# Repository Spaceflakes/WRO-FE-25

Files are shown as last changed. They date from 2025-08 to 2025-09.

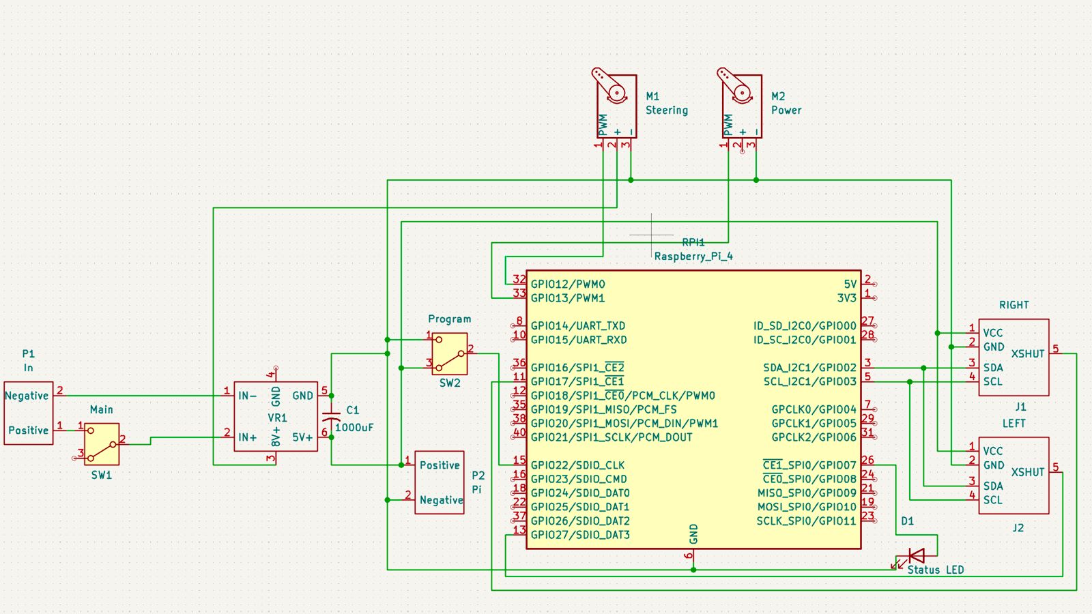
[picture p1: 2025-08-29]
schemes/Schematic Diagram.jpeg

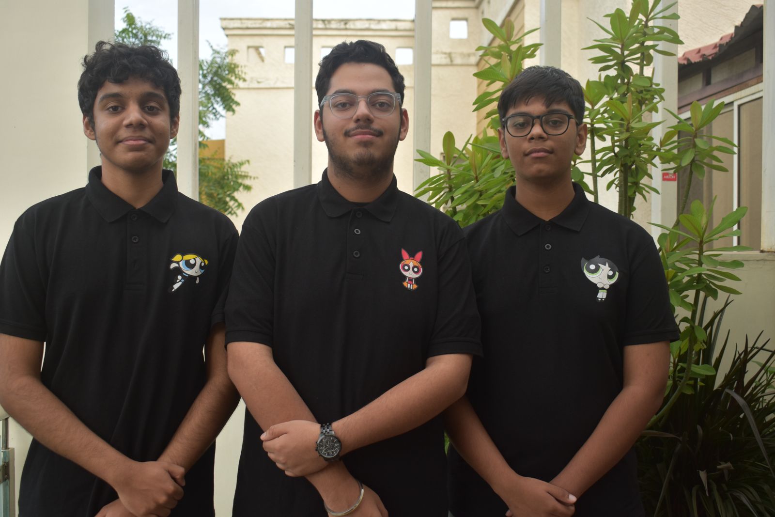
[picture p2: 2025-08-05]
t-photos/Formal.jpg

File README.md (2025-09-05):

<div align="center">
	
# WRO-25

# The Powerpuff Trio

Powerpuff_girls_wallpaper-removebg-preview

**_The offical repo of The Powerpuff trio for WRO-FE 2025_**
</div>
	
## Content
### **Folders**
* `t-photos` contains 1 formal image and 2 informal images
* `v-photos` contains 6 photos of the vehicle (from every side, from top and bottom)
* `video` contains the video.md file with the link to a video where driving demonstration exists
* `schemes` contains schematic diagrams of components illustrating all the elements (electronic components and motors) used in the vehicle and how they connect to each other, along with the models of the PCB.
* `src` contains code of control software for all components which were programmed to participate in the competition
* `models` is for the files for 3D models used by to produce the vehicle elements.

### **Index**
 [The Powerpuff Trio](#The-Powerpuff-Trio) 
   
   - Members
   
   - Small introduction to them

   - Team Pictures

[Vehicle Photos and Video](#Vehicle-Photos-and-Video)

- Shows the vehicle from all 6 sides and shows a smaple video of it working
   
 [Hardware Materials](#Hardware-Materials)

 - Name of parts

 - Links

 - Rate per part

 [Mobility Management](#Mobility-Management)
 
 - Gives an overview of our bots parts

[Design](#Design)

- Tells how every component is placed. 

[Power Management and Sense Management](#Power-Management-and-Sense-Management)

  - Gives an overview about the power consumption of our bot and use of each sensor

[Schematic Diagram](#Schematic-Diagram)

 - Shows all connections between the parts

[Obstacle Management](#Obstacle-Management)

- Basic overview of our strategy

- Shows our logic for dectecing the pillars and parking logic

[Our Journal](#Our-Journal)

- Tells our jounery making the bot

## The Powerpuff Trio 
Members:
1) Vedant Varshney

11th Grader in Billabong High International School. First time participating in WRO but has participated many other robotic compenitions. Controlling the making of the github  and helping in other miscellaneous tasks

2) Siddesh Jain

11th Grader in Billabong High, second time in WRO, the lead engineer and the head of the developement team, responsible for the CAD and all the choices. Races FPV drones and likes math. Also is an idiot.
   
3) Sohaan Chhabra

A 12th grader at Billabong High International School. Returning WRO participant. Handles the logic, simulations, camera and LiDAR processing — basically speaks to AI more than humans. Also, races drones just to relax.

### Team Pictures

#### Formal



#### Informal



Informal - 2

# Vehicle Photos and Video

#### Photos

Back View

Front view

Side View 2

Side View 1

Bottom View

Top View

> [!NOTE]
> We replaced the zipties that strapped on the batteries to the bot with velcro straps.

#### Videos

https://youtu.be/7fzDv5zbyI8?si=_J0dI-LTaZbQbC20

## Hardware Materials

| Name |	Link |	Rate per part (in Rs.) |
|---|---|---|
| Rpi 4B/5	| https://www.raspberrypi.com/products/raspberry-pi-5 | -	|	
| LiDAR	| https://robu.in/product/ydlidar-x4-pro-360-degree-ros-scanner-for-navigation-collision-avoidance-10m/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	| 8159 |	
| Servo	| https://robu.in/product/surpass-hobby-25kg-s2500m-servo/	| 1500 |	
| Wheels |	https://robu.in/product/65mm-robot-smart-car-12-rim-wheel-blue/ |	167 |	
| Pi Camera	| https://robu.in/product/arducam-8mp-imx219-175-degree-ultra-wide-angle-raspberry-pi-camera-module-compatible-with-raspberry-pi-4-model-b-pi-3-3b-and-pi-zero-2w/ |	2090	|	
|Stepdown Module | https://robu.in/product/mini560-dc-5v-5a-step-down-stabilized-module/ | 94 |		
| ESC + Motor |	https://www.hobbywingdirect.com/collections/quicrun-brushless-system/products/quicrun-wp-10bl120-sl-system-g2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 |	15000 |	
| Battery |	- |	1500 |		
| Gears | - |	2500 |		
| PCB | - |	2000 |		
| CF | - |	1500 |	

### PCB Design & Prototype PCB

##### Prototype PCB

WhatsApp Image 2025-08-23 at 5 41 59 PM

##### PCB Design





## Mobility Management

Our self-driving vehicle utilizes a rear-wheel drive (RWD) configuration, where both rear wheels are powered by a single brushless DC motor via a unified drivetrain and a robust 6:1 gear reduction. The wheels are 65 mm in diameter, providing an optimal balance between ground clearance and acceleration. Steering is accomplished using a high-torque Surpass Hobby 25kg S2500M servo mechanically linked to the front wheels through a precision steering linkage, under PWM control from a Raspberry Pi single-board computer.

The chassis is built from a unified bottom plate, providing a lightweight yet rigid foundation that maintains dimensional stability under load. All components are secured via counter-sunk steel screws, ensuring minimal chassis flex and maximum durability in high-dynamic maneuvers.

Speed, torque, and power calculations:

With a 6:1 gear reduction from the motor to the driving wheels, and a wheel diameter of 65 mm, the theoretical speed and torque can be calculated as follows:

Assume maximum motor RPM (post-gear reduction): 3000 RPM (typical for RWD brushless at this voltage/gear)

Wheel circumference: 
C = π × D

= 3.1416 × 0.065m ≈ 0.204m

At 3000 RPM at the wheel:

Linear speed: 
V = RPM × C / 60

= 3000 × 0.204 / 60 ≈ 10.2m/s  (36.7 km/h theoretical, but likely to operate at much lower speed for control and safety)

Since the gear ratio is 6:1, torque at the wheel is multiplied by 6 relative to the motor's output. If the motor provides 0.3 Nm, at the wheels this becomes 

0.3 × 6 = 1.8Nm

This setup allows for both quick acceleration and sufficient torque to manage sharp turns and inclines, which is crucial for obstacle navigation and parallel parking accuracy.

The ESC (Hobbywing Quicrun WP-10BL120, G2) regulates current delivery (up to 60A) for smooth and responsive throttle input, while PWM control from the Pi enables fine-grained speed and direction regulation.

In summary, the chassis, drivetrain, and steering are holistically integrated to provide robust, agile, and precise mobility

> [!NOTE]
> We initially selected a carbon fiber chassis for its high strength-to-weight ratio but switched to a simpler material because precise cutting was difficult with our tools. To streamline development, we also opted not to include ToF sensors, using LiDAR and Pi Camera that simplify integration while still delivering reliable obstacle detection and navigation performance, fully in line with competition rules and judging criteria.

 ## Design

We mounted the LiDAR sensor on top of the ESC to ensure that its readings remain accurate and free from interference caused by other components. Since there was limited space in the center of the robot, we attached the two batteries securely on the sides using Velcro straps, which provide both stability and ease of removal. Beneath the LiDAR, the ESC is positioned to maintain a compact arrangement. The motor is placed near the rear wheels for efficient power transmission, while the servo, responsible for steering, is located between the front wheels to allow precise control of direction. The PCB board is carefully installed between the ESC and the front wheels in its own compartment to optimize wiring and accessibility. Our robot uses wheels with a diameter of 65 mm, balancing maneuverability and stability on the track and its overall dimensions of 280 mm in length, 175 mm in width, and 95 mm in height. Additionally, the camera is mounted on the front wing, providing a clear and unobstructed view ahead to assist with navigation during the autonomous run.

## Power Management and Sense Management

The propulsion and actuation circuits (ESC, motor, servo) are supplied by one LiPo battery. The ESC has a peak draw of 60A (operating at ~50%, or 30A continuous, during typical run), consuming a maximum of 14.8V × 30A = 444 W. The servo draws 10W at peak, and the combined power budget for the actuation side is kept within the safe limits by the battery’s discharge rating.

The Raspberry Pi and sensitive sensors (including Lidar and IMU) are isolated on the second 4S LiPo, with a DC-DC converter regulating voltage to 5V/3A as required for stable logic and communication. The Pi and Lidar each typically consume 12.5W (2.5A @ 5V per spec), ensuring ample runtime and reliable operation under competition conditions.

Wire gauge and power distribution are selected to minimize resistive losses, and all high-current connections use gold-plated connectors and fuses for safety and performance.

Sensor Suite Includes:

Lidar (12.5W): Primary for localization, mapping, and pillar/tracking detection in the obstacle challenge.

Raspberry Pi Camera (CSI-2): Used for vision-based lane detection and traffic sign/pillar color classification.

IMU (connected to Pi): Fusioned with odometry for accurate heading and slip detection.

All sensor data are fused on the Pi SBC, providing robust perception for navigation algorithms.

The Pi implements PWM control for motor speed and servo position, interfacing via logic-level converters with both the ESC and servo. Data logging, sensor fusion, and vehicle state estimation are performed real-time for optimal trajectory planning and reliability in both open track and obstacle challenges.

Power consumption summary during operation:

| Component | Power (W) | Power Source |
|---|---|---|
| ESC & Motor |	222	| 4S LiPo #1 |
| Servo | 10 | 4S LiPo #1 |
| Lidar | 12.5 | 4S LiPo #2 (DC-DC 5V) |
| Raspberry Pi | 12.5 | 4S LiPo #2 (DC-DC 5V) |
| Sensors (misc) | < 5 | 4S LiPo #2 (DC-DC 5V) |

## Schematic Diagram



## Obstacle Management

### Strategy

1) We are using a mix of LiDAR and the Pi Camera sensors which enables obstacle avoidance.

- LiDAR offers highly accurate 3D mapping, critical for safe navigation and obstacle detection.

- Cameras provide detailed 2D imagery, that complements the 3D data from LiDAR.
  
2) We are using ROS 2 as our main programming framework because it provides a modular and real-time system that connects all our sensors efficiently. This setup ensures smooth communication and coordination between the hardware and software, allowing our system to respond quickly and reliably. Additionally, ROS 2 makes it easy to expand and add new features as the project grows. Overall, ROS 2 gives us a flexible and robust platform suited for developing our project.

By combining these technologies, we achieve a robust perception system that enhances accuracy, safety, and reliability in autonomous vehicle operation.

### Logic
Open Challenge (Round 1)
1) ROS 2 Node Initialization

   - All system modules and ROS 2 nodes (including motion, perception, and sensor fusion) are launched.

2) Start Switch Monitoring

   - The robot waits in an idle state until it receives the official start switch input.

3) Lane Navigation & Dynamic Obstacle Avoidance Loop

- The vehicle drives forward, continuously evaluating the distances to the side walls.

- If both sides readings > 2.8m, the bot turns gently toward the side with the higher clearance to maintain centrality and avoid collision.

- The LiDAR module operates in parallel, providing high-frequency wall distance measurements. These are used in a feedback loop for counter-steering—dynamically correcting to keep the chassis parallel to the lane boundaries and maximizing lap speed and safety.

4) Lap Counter & Completion Logic

- Each complete revolution of the track increments a lap counter.

- If laps > 3, the system initiates the Parallel Parking Sequence. Otherwise, the navigation loop repeats.

Obstacle Challenge (Round 2)
1) LiDAR-Based Mapping & Pillar Detection Initialization

- The LiDAR system bootstraps, performing environmental scans to map both static field features and dynamic obstacles (pillars).

2) Pillar Tracking & Color Classification

- Upon locating a pillar by proximity in the LiDAR map, the camera is triggered to capture and classify the pillar’s color by majority pixel average.

- If green, a navigation waypoint is generated to the left of the pillar; if red, to the right.

- Waypoints are fed to the main path-planner, which recalculates trajectories dynamically for precise lane-keeping and object avoidance.

3) Loop Logic for Laps

- The above mapping, classification, and navigation run continuously throughout the three laps, with the robot always tracking its section, progress, and upcoming pillar positions.

4) Autonomous Parallel Parking Sequence

- Parking Lot Detection: At lap completion, sensors (LiDAR/camera) search for the parking lot boundary markers as per field specs.

- Initial Alignment: The vehicle slows, aligning itself parallel to the field’s outer wall by continuously comparing left/right LiDAR readings and using IMU orientation checks (< 2cm and < 2° tolerance).

- Entry Positioning: Advance until the rear wheel crosses the intended parking zone entry (based on rotary encoder ticks or real-time field feature estimation).

- Reverse Maneuver, Step 1: Start reversing with maximum steering toward the parking bay (usually right).

- Reverse Maneuver, Step 2: Once halfway inside, immediately steer to full opposite lock (left), continuing the reverse arc.

- Final Alignment: Stop as soon as sensors (LiDAR/camera) confirm the entire robot is within boundaries and parallel to the wall (verify < 2cm tolerance). If needed, issue slight forward/backward correction maneuvers using PID feedback from the sensors.

- Completion: Power down drive motors and alert completion via buzzer/LED.

### Flow Charts

##### Open Round

Mermaid Chart - Create complex, visual diagrams with text A smarter way of creating diagrams -2025-08-23-150618

##### Obstacle Round

Mermaid Chart - Create complex, visual diagrams with text A smarter way of creating diagrams -2025-08-23-152100

## Our Journal

### June:

- This month, we focused on event preparations. We decided on our team name, drafted the initial design of our car, and began placing orders for the required parts.

##### The Original Sketch of our car.

WhatsApp Image 2025-04-30 at 11 18 56 PM

## July:

- This month, we initiated 3D printing for our parts and began receiving the components we had previously ordered. Construction of the car officially started during this period. In the later weeks of July, we also began the coding process.
  
##### The car by the end of the month

  

## August:

- By the beginning of August, we had completed both the construction and coding phases, and then started testing, during which we fine-tuned everything to ensure the car was ready for the event.

  (pic of the final desgin of the bot)

## Gantt Chart



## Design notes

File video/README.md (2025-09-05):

Video
====
Shows sample video of our bot

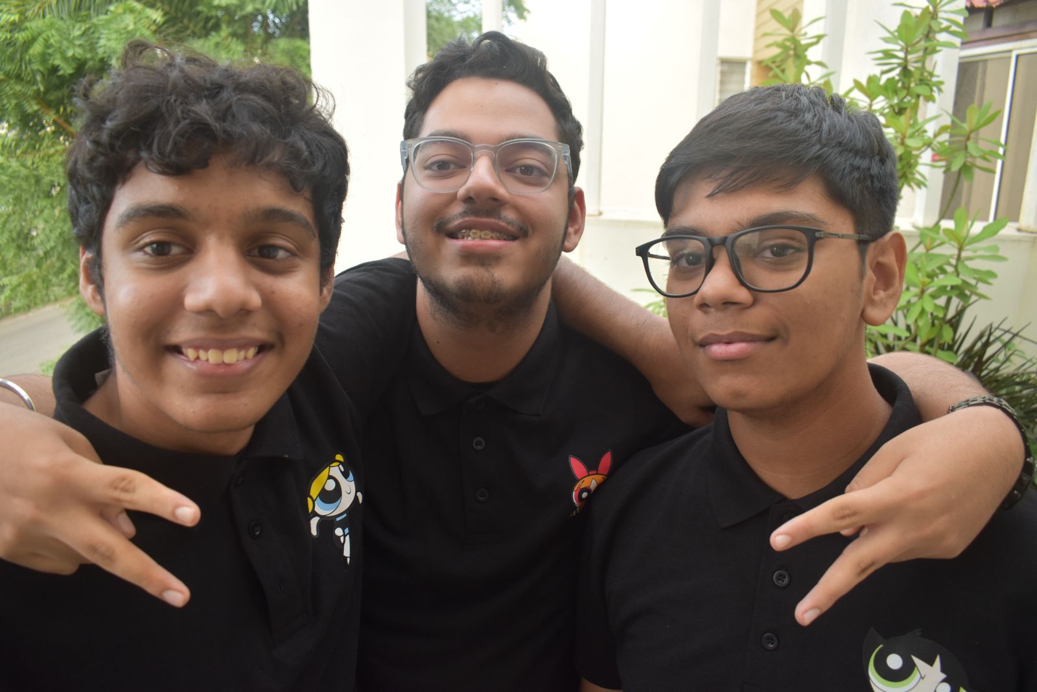
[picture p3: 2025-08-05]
t-photos/Informal - 1.jpg

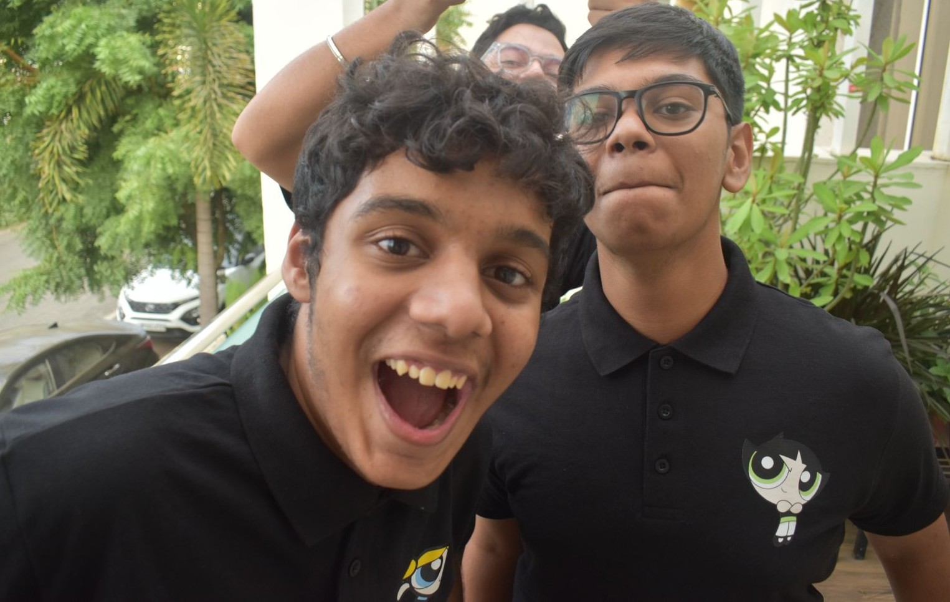
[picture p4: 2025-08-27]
t-photos/Informal - 2.jpeg

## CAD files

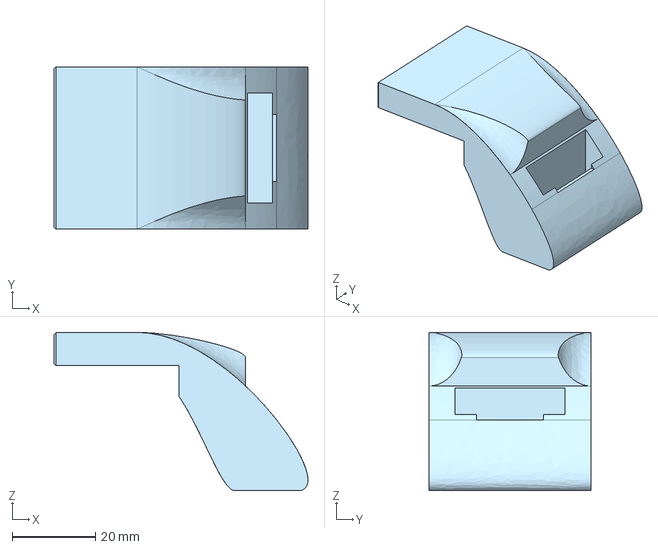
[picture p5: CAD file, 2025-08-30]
models/Cam mount_F.step
61.0 x 39.0 x 38.0 mm

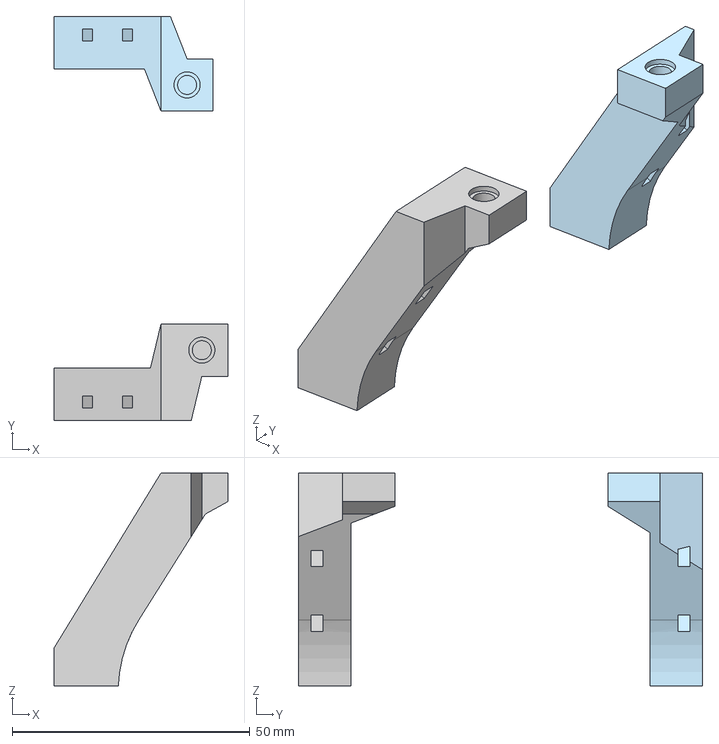
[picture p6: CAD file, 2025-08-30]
models/LiDAR Mount_F.step
36.6 x 85.0 x 44.8 mm

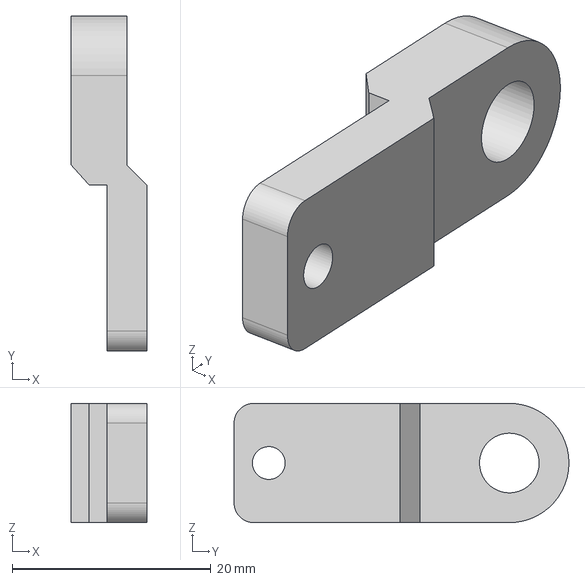
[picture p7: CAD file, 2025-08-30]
models/Servo Horn_F.step
7.60 x 33.7 x 12.0 mm

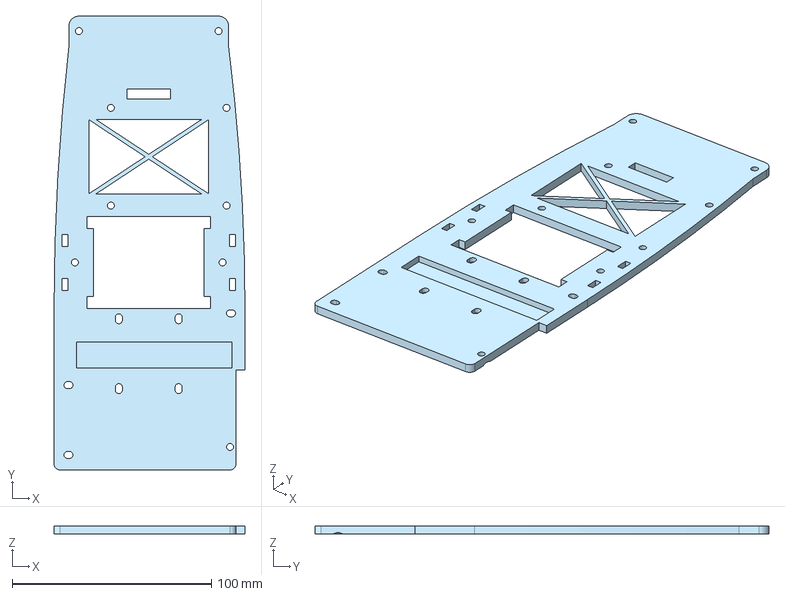
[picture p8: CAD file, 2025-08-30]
models/Bottom plate_F.step
95.8 x 227.5 x 4.00 mm

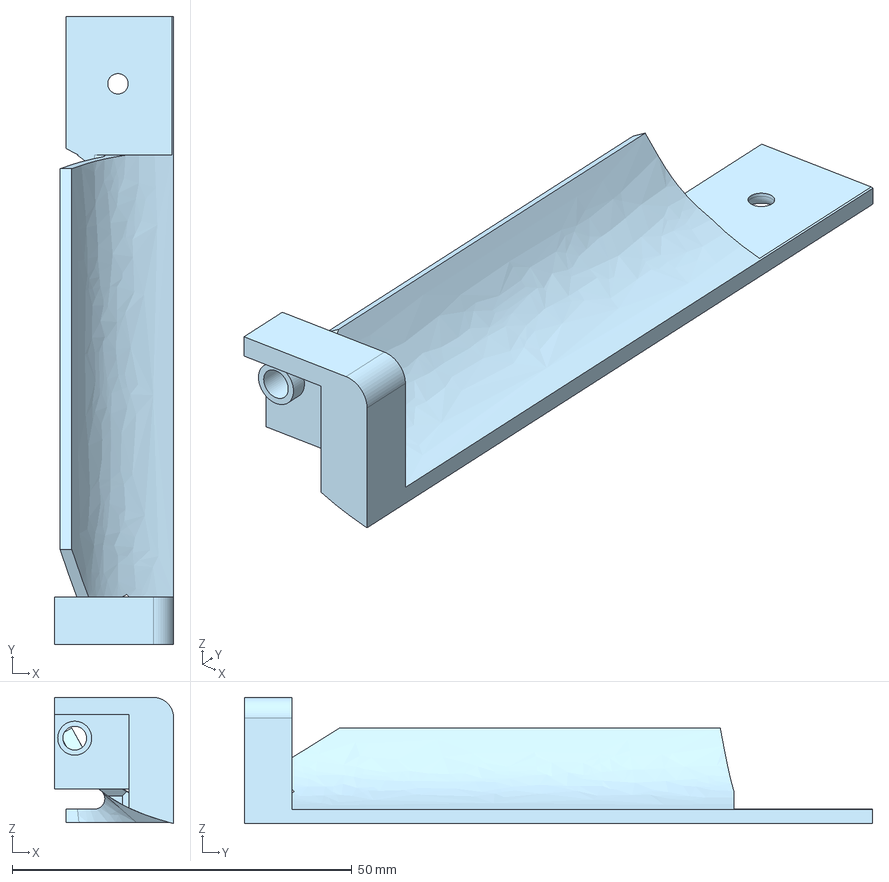
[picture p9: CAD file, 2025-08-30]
models/Wing Ends R_F.step
17.6 x 92.4 x 18.6 mm

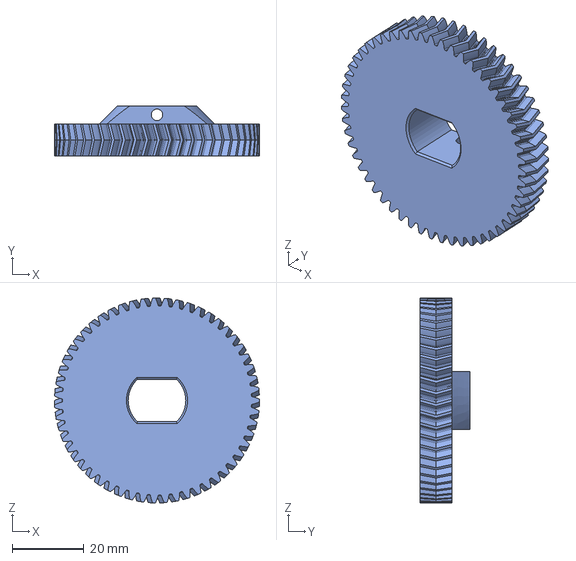
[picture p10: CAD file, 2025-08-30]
models/Gear 2_F.step
57.0 x 14.0 x 57.0 mm

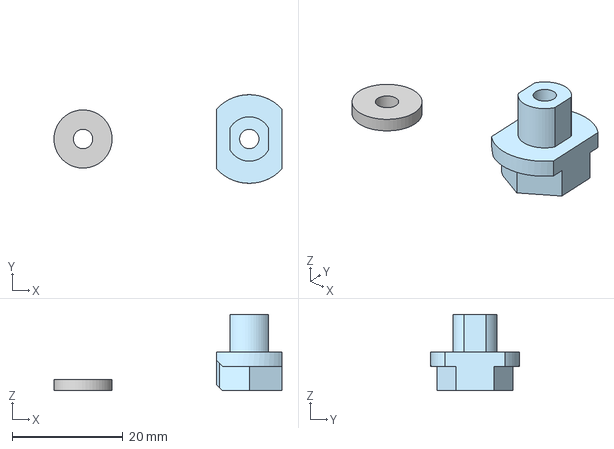
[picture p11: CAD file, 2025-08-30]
models/Front Wheel Connector_F.step
41.1 x 16.0 x 13.8 mm

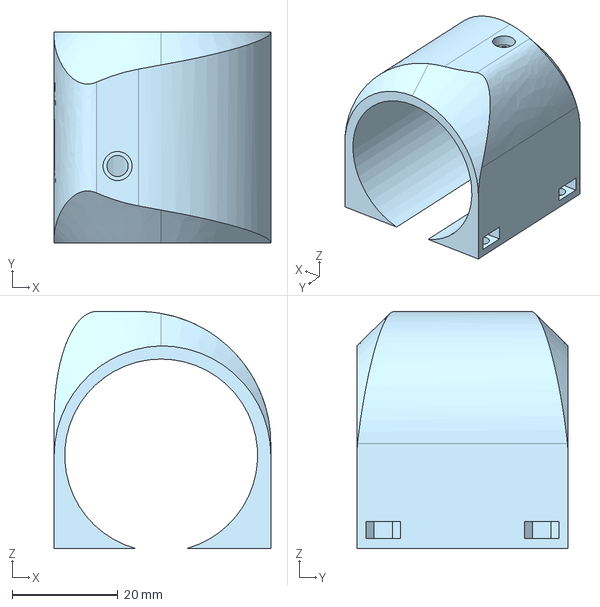
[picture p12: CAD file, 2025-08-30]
models/Motor Mount_F.step
41.0 x 40.0 x 44.9 mm

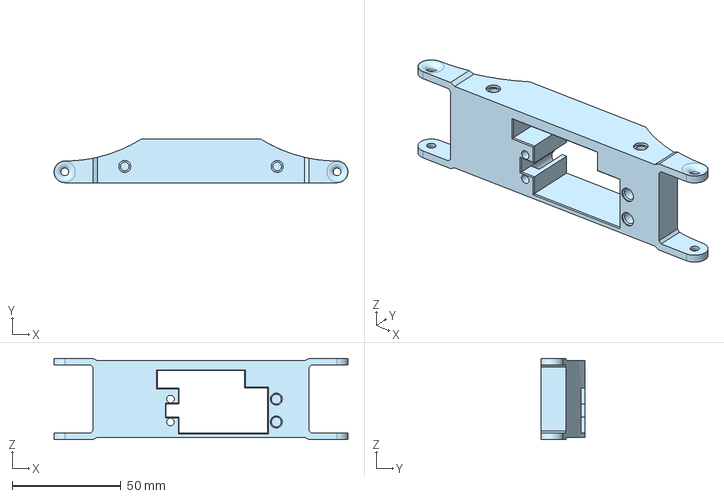
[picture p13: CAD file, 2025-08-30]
models/Front wheel mount_F.step
135.0 x 20.0 x 37.2 mm

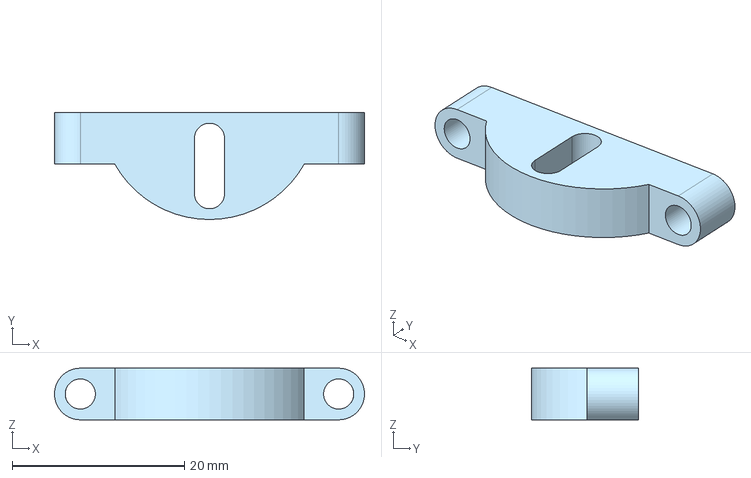
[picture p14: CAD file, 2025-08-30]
models/Steering Center_F.step
36.0 x 12.4 x 6.00 mm

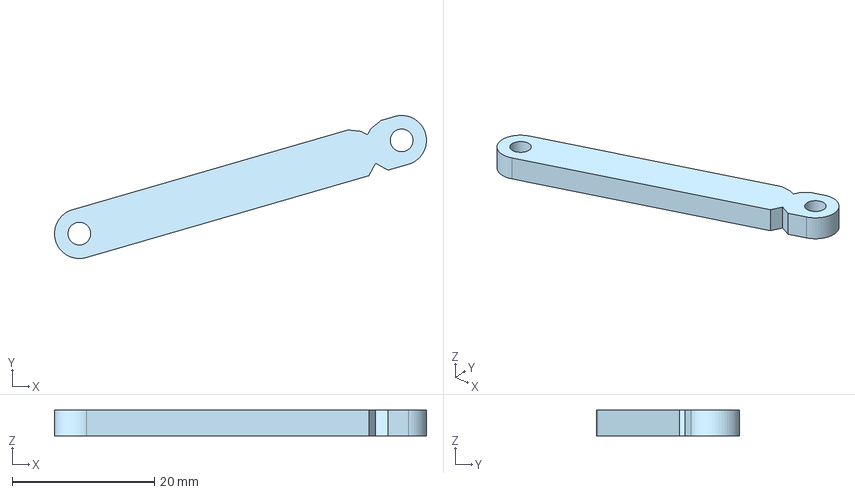
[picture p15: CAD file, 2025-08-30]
models/Stering linkage_F.step
52.4 x 20.1 x 3.60 mm

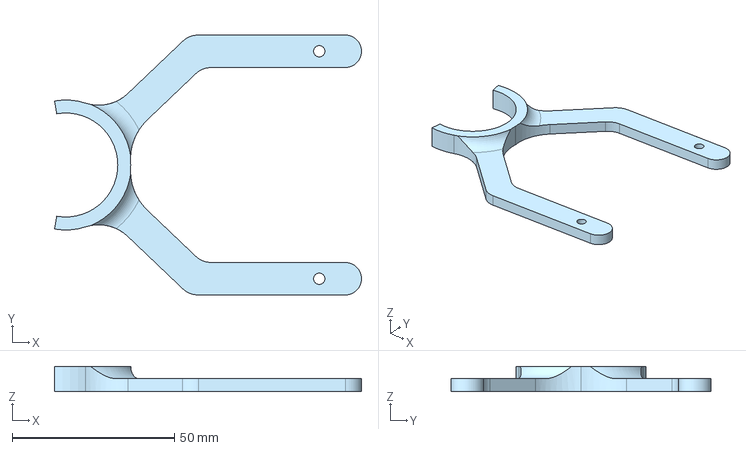
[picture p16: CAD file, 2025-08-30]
models/Top Brace_F.step
94.5 x 80.0 x 7.80 mm

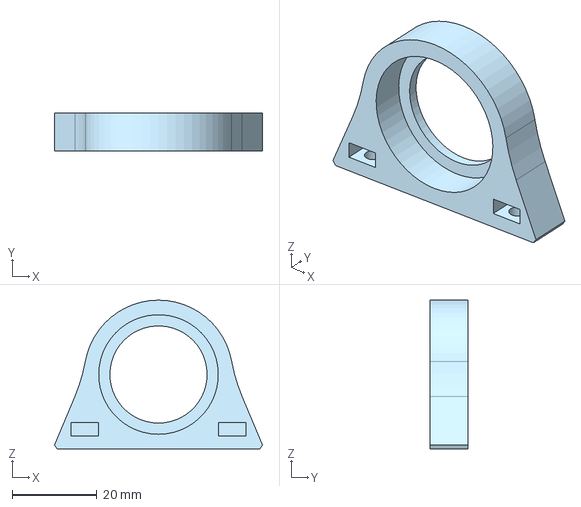
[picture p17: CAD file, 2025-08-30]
models/Rear Left Mount_F.step
49.2 x 9.00 x 35.2 mm

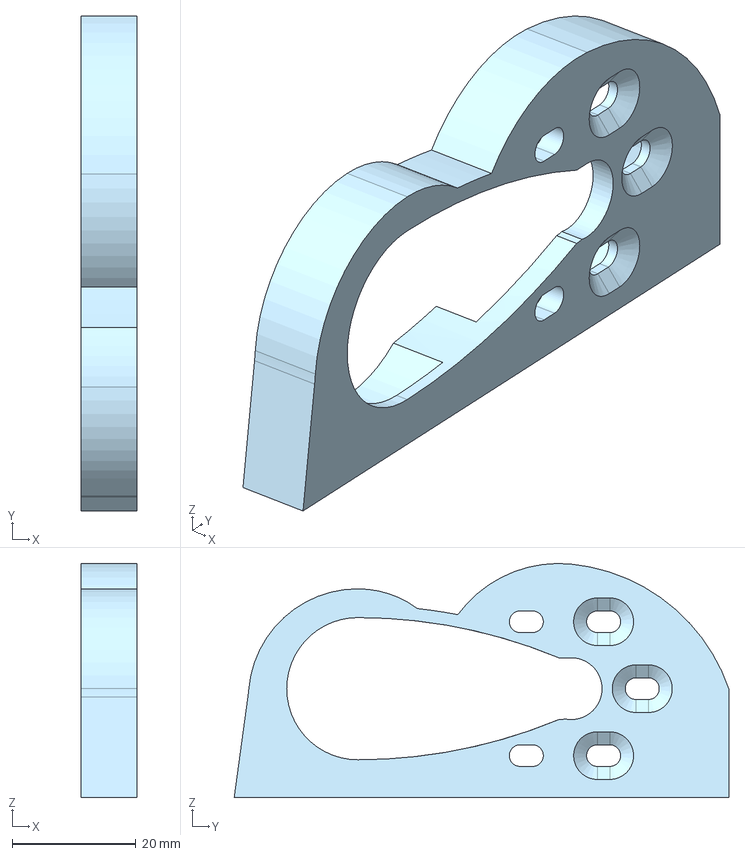
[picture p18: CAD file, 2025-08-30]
models/Rear Right Mount_F.step
9.00 x 80.0 x 37.8 mm

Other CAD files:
models/Wing End L_F.step
models/Font wheel interface_F.step
models/Gear 1_F.step
models/Rear Axel_F.step

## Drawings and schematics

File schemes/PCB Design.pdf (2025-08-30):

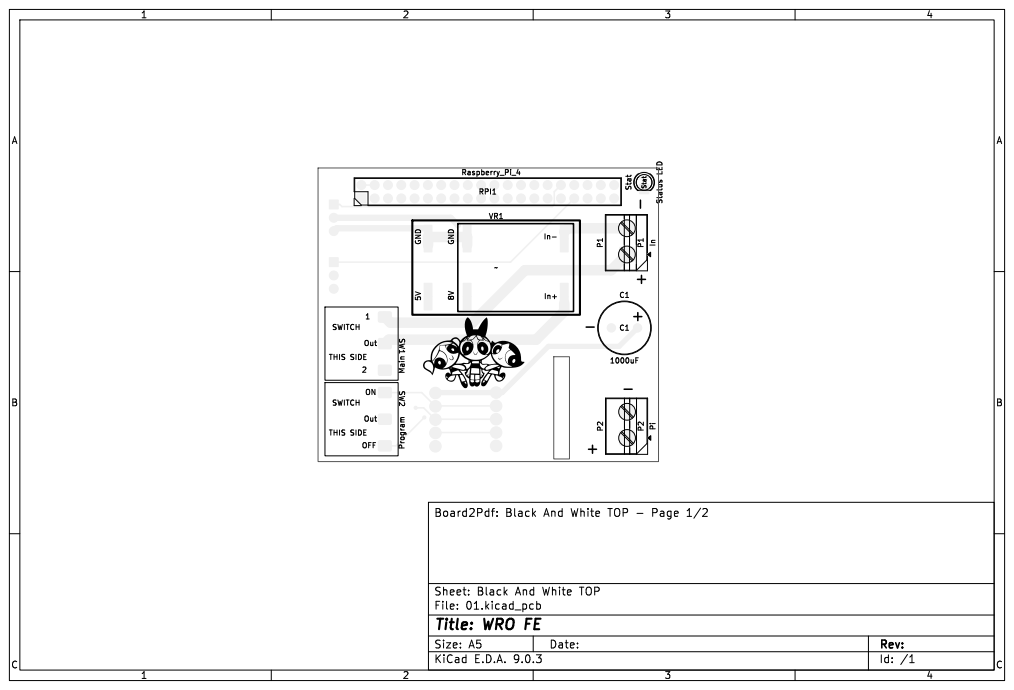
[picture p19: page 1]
- - ++ + SW1 THIS SIDE1 SWITCH Out 2; VR1 GND 5V; In+ GND; Pi Raspberry_Pi_4; In SW2 ON Out THIS SIDEOFF SWITCH; Stat 1; 4 ABC; ABC Date: KiCad; E.D.A. 9.0.3 Size: A5; Rev:; File: 01.kicad_pcb Sheet:; Black; And; White; TOP; Board2Pdf:; And White; TOP -; Page; 1/2 Main; P² RPI1; P¹ Program; Status LED Stat

Id: /1 Title: WRO FE

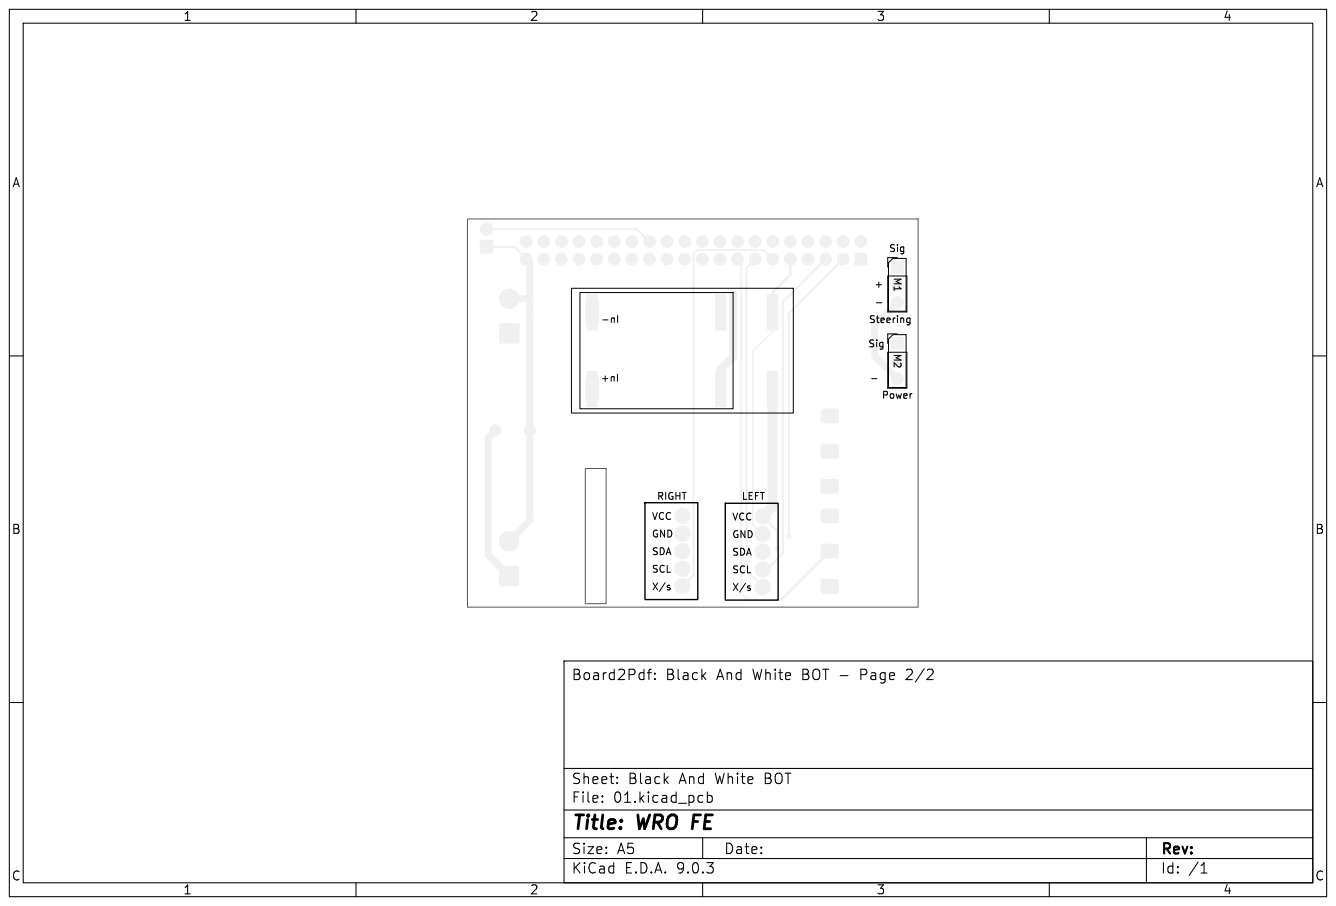
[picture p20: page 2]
Sig; SDA; SCL; Steering RIGHT X/s SDA; VCC GND; Power 1; BC Date: KiCad; E.D.A. 9.0.3 Size: A5; Rev:; File: 01.kicad_pcb Sheet:; Black; And; White; BOT Board2Pdf:; And White; BOT -; Page 2/2 M1 M2

Id: /1 Title: WRO FE

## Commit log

2025-08-04 Update README.md
    changes to hardware material and index
2025-08-30 3D models
    [Bottom plate_F.step, Cam mount_F.step, Font wheel interface_F.step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]
